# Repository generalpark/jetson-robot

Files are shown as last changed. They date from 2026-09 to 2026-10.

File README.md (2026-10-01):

# Jetson ROS2 Robot

사람이 말로 준 주행 명령을 **로봇 안의 언어모델**이 제어 명령으로 바꾸고, **ESP32가 모터를 돌리는** 로봇을
부품 선정부터 펌웨어 · 모델 학습 · 엣지 추론 최적화까지 직접 만든 기록입니다.
연산은 Jetson Orin Nano, 실시간 제어는 MCU로 나눴습니다.

> 🚧 2026-10-01 기준 — 제어부 · 모델 · 추론 최적화 완료, 문장 → ESP32 경로 연결 확인. 조립 · 실주행 전

---

## 한눈에

| 영역 | 결과 | 자세히 |
|---|---|---|
| **펌웨어** | BTS7960 단락 방지 순서 강제, 500ms 무명령 시 자동 정지, 20kHz PWM을 계측 장비 없이 검증 (최대 오차 **1.25%p**) | [firmware/](firmware/README.md) |
| **모델 학습** | 자연어 → ROS 2 Twist JSON. 값 정확도 few-shot **2.0% → LoRA 74.7%** (전체 파라미터의 1.75%만 학습) | [finetune/](finetune/README.md) |
| **안전** | "오늘 날씨 어때"에도 움직이던 문제. 거부 학습으로 주행 아닌 문장 60건 중 움직임 **57~100% → 0%**, 학습 어휘 정확도 100% 유지 | [finetune/](finetune/README.md#주행이-아닌-문장-거부-2026-10-01) |
| **재현성** | 한 번씩 학습해 본 "거부 학습 후 −3.4%p"를 시드 3회로 다시 재니 편차(같은 설정도 70~80%)였다. 확신도 되묻기는 부호 오류를 절반으로 줄이지만 모델이 확신을 갖고 틀려 기본값에선 뺐다 | [finetune/](finetune/README.md#시드-반복--한-번-학습한-비교는-믿을-수-없었다-2026-10-01) |
| **평가 설계** | 검증 손실 0.000027이지만 학습 어휘 **100%** vs 미학습 어휘 **49.3%**. 오답 38건 전부 미학습 어휘 | [finetune/](finetune/README.md) |
| **엣지 추론** | **4,115ms → 408ms (10.1배)**, 모델 942 → 374MB, 정확도 −0.7%p. 병목 4개를 측정으로 하나씩 제거 | [BENCHMARK](finetune/BENCHMARK.md) |
| **경로 통합** | 문장 → ESP32 수신까지 실측. 드문드문 오는 요청은 GPU 클럭이 안 올라 **810 → 420ms**(서버 동작 중에만 클럭 고정). 주행 시간이 ROS 기동 시간만큼 짧아지던 버그 수정. 상주 브릿지로 **2.5 → 0.6초**, 달리는 중 정지 0.17초 | [BENCHMARK](finetune/BENCHMARK.md#실제-주행-경로에서-2026-10-01) |
| **장애 진단** | 학습 중 무로그 재부팅. 전원 가설을 측정으로 기각하고, PyTorch 캐시 팽창(5.6GB)이 원인임을 찾아 해결 | [finetune/](finetune/README.md#학습-중-보드-리셋--원인은-메모리였다) |

---

## 전체 흐름

```
 "앞으로 천천히 3초 동안 가"
          │
          ▼   Jetson Orin Nano 8GB
 ┌───────────────────────────────┐
 │ Qwen2.5-0.5B + LoRA           │  → {"linear": 0.15, "angular": 0.0, "duration": 3.0}
 │ llama.cpp Q4_K_M (상주 서버)  │
 └───────────────────────────────┘
          │  ROS 2 /cmd_vel (geometry_msgs/Twist)
          ▼
   micro-ROS Agent ──USB 시리얼──▶ ESP32 ──PWM 20kHz──▶ BTS7960 ×2 ──▶ DC 모터 ×4
```

`firmware/nl2cmdvel.sh` 한 줄로 이 경로 전체가 실행됩니다. 모델과 ROS 노드가 모두 상주해,
문장 입력부터 ESP32가 첫 명령을 받기까지 **0.6초**(처음 연결했을 때 2.2~2.7초)입니다.
"멈춰" 같은 정지어는 모델을 거치지 않고 **0.17초** 만에 진행 중인 명령을 덮어씁니다.

---

## 시스템 구조

```
┌─────────────────────────┐        ┌──────────────────────┐
│  Jetson Orin Nano 8GB   │        │   ESP32 DevKitC      │
│                         │ USB    │                      │
│  · ROS2 Humble          │◄──────►│  · micro-ROS Client  │
│  · 명령 해석 (언어모델)   │ serial │  · PWM 모터 제어      │
│  · micro-ROS Agent      │115200  │  · 무명령 시 자동 정지 │
└─────────────────────────┘        └──────────────────────┘
         │                                    │
    카메라 / IMU                        모터 드라이버 ×2
                                              │
                                        DC 모터 ×4 (엔코더)
```

**왜 분리했는가** — 모터 PWM 제어와 엔코더 펄스 카운트는 수 μs 단위의 응답이 필요한데, 리눅스 유저스페이스는 이를 보장하지 못합니다. 실시간성이 필요한 루프는 MCU에 두고, Jetson은 인지·판단만 담당하도록 역할을 나눴습니다. 두 계층은 micro-ROS로 이어져 ROS2 토픽으로 통신합니다.

---

## 하드웨어 구성과 선정 근거

| 부품 | 선정 | 근거 |
|---|---|---|
| **연산** | Jetson Orin Nano 8GB | 온디바이스 추론을 위한 GPU 필요 |
| **MCU** | ESP32 DevKitC (WROOM-32D, CP2102) | micro-ROS 지원 확인. **WROOM-32U는 외부안테나형, ESP32-P4는 micro-ROS 미지원**이라 제외 |
| **모터** | JGA25-370 12V 170RPM, 엔코더 내장 ×4 | 홀 엔코더 11PPR × 감속비 35 = **바퀴 1회전당 385펄스**. 오도메트리 분해능 확보 |
| **드라이버** | BTS7960 (IBT-2) ×2 | 좌/우 각 2모터 병렬 구동 |
| **카메라** | IMX219 120° **22핀** | Orin Nano는 22핀 CSI. 15핀 모듈은 변환 케이블이 추가로 필요 |
| **IMU** | MPU6050 | 자세 추정 |

### 전원 설계

모터와 연산 장치의 전원을 **물리적으로 분리**했습니다.

- **모터계** — 12V 18650 3S2P (BMS 내장)
- **연산계** — USB-PD 파워뱅크 + PD 트리거 케이블

분리한 이유는 두 가지입니다. 첫째, 모터 기동 시 순간 전류가 크게 흘러 연산 장치의 전압이 흔들립니다. 둘째, **대부분의 파워뱅크는 2포트를 동시에 쓰면 출력이 5V로 강등**되는데, Jetson은 9~20V 입력을 요구하므로 한 배터리에서 둘 다 뽑으면 부팅 자체가 불안정해집니다.

---

## 셋업 과정에서 해결한 것

### Docker 데이터 경로를 NVMe로 이전
jetson-containers 이미지는 개당 10~15GB입니다. 64GB microSD로는 두 개도 못 올립니다.
NVMe SSD를 `/mnt/nvme`로 마운트하고 Docker `data-root`를 그쪽으로 옮겼습니다. `default-runtime`을 `nvidia`로 지정해 컨테이너에서 GPU를 바로 쓸 수 있게 했습니다.

### L4T 패키지 버전 고정
`apt upgrade`가 `nvidia-l4t-*` 패키지를 건드리면 CUDA 환경이 깨지고 부팅이 안 되는 사례가 보고돼 있습니다.
관련 패키지 55개를 `apt-mark hold`로 잠갔습니다. 일반 패키지 설치는 그대로 가능합니다.
같은 이유로 `torch.compile`에 필요한 Triton을 맞추려 PyTorch를 올리지 않고, C++ 런타임(llama.cpp)으로 우회했습니다.

### 학습 중 메모리 상한
Jetson에는 전용 VRAM이 없어 GPU가 시스템 RAM을 나눠 씁니다. PyTorch 캐싱 할당기를 그대로 두면
학습 중 5.6GB까지 불어나 OS가 멈췄습니다. 학습 스크립트는 기본으로 할당기에 상한(60%)을 겁니다.

### 전력 모드
`nvpmodel -m 2` (MAXN_SUPER)로 설정해 CPU 1.73GHz / GPU 1020MHz를 사용합니다.

### 시리얼 권한
ESP32(CP2102) 인식을 위해 `cp210x` 드라이버 로드를 확인하고, 사용자를 `dialout` 그룹에 추가해 `sudo` 없이 시리얼에 접근하도록 했습니다.

---

## 저장소 구조

```
firmware/    ESP32 펌웨어 — 시리얼 단독 테스트용(motor_ctrl), micro-ROS 노드(motor_uros),
             자연어 → /cmd_vel 스크립트(nl2cmdvel.sh)
finetune/    데이터 생성 · LoRA 학습 · 평가 · 추론 최적화 · 진단 스크립트, 측정 기록
scripts/     Jetson 쪽 USB 확인, micro-ROS Agent, 명령 해석 서버(llama-server), ROS 2 셸
```

## 스크립트

| 스크립트 | 용도 |
|---|---|
| `scripts/check_usb.sh` | ESP32(USB 시리얼) 인식 확인 — 장치 노드, `lsusb`, 커널 로그를 한 번에 |
| `scripts/uros_agent.sh` | micro-ROS Agent 실행 (컨테이너) |
| `scripts/llama_server.sh` | 명령 해석 모델(Q4_K_M) 상주. 떠 있는 동안만 GPU 최저 클럭 고정, 종료 시 원복 |
| `scripts/cmd_bridge.sh` | `/cmd_vel` 브릿지 상주. 명령을 로컬 TCP로 받아 10 Hz 발행, 새 명령이 진행 중 명령을 덮어씀 |
| `scripts/ros2sh.sh` | ROS2 셸 진입 — 토픽 확인용 |

### 통신 검증 순서

```bash
./scripts/check_usb.sh          # /dev/ttyUSB0 인식 확인
./scripts/uros_agent.sh         # 터미널 A — Agent 대기
./scripts/ros2sh.sh             # 터미널 B
  └─ ros2 topic list            # ESP32가 만든 토픽이 보이면 성공
```

> micro-ROS Agent 옵션은 `--dev`가 아니라 **`-D`** 입니다. 문서마다 다르게 적혀 있어 실행이 안 되는 원인이 됩니다.

> ESP32는 **부팅할 때 한 번만** Agent에 접속합니다. Agent를 먼저 띄운 뒤 ESP32의 EN(리셋) 버튼을 누르세요.

### 자연어 주행

```bash
./scripts/uros_agent.sh                           # 터미널 A — Agent (띄운 뒤 ESP32 리셋)
./scripts/llama_server.sh                         # 터미널 B — 명령 해석 서버
./scripts/cmd_bridge.sh                           # 터미널 C — /cmd_vel 브릿지
./firmware/nl2cmdvel.sh "앞으로 천천히 2초 동안 가"   # 터미널 D
./firmware/nl2cmdvel.sh "멈춰"                     # 달리는 중에도 바로 정지
```

---

## 환경

| | |
|---|---|
| L4T | R36.4.3 (JetPack 6.2) |
| 커널 | 5.15.148-tegra |
| CUDA | 12.6 |
| PyTorch | 2.4.0 (NVIDIA Jetson 빌드, 컨테이너) |
| llama.cpp | CUDA 빌드, `sm_87` |
| ROS2 | Humble |
| micro-ROS Agent | `microros/micro-ros-agent:humble` |
| ROS2 이미지 | `dustynv/ros:humble-ros-base-l4t-r36.3.0` |

---

## 진행 상황

- [x] Jetson 개발 환경 구축 (JetPack 6.2, NVMe 이전, 패키지 고정)
- [x] micro-ROS Agent 컨테이너 구동, 시리얼 드라이버·권한 설정
- [x] 하드웨어 사양 선정
- [x] ESP32 펌웨어 — PWM 모터 제어, 드라이버 단락 방지, 통신 단절 시 정지, PWM 자가검증
- [x] micro-ROS `/cmd_vel` 구독 · 차동 구동 변환
- [x] 자연어 → 제어 명령 모델 학습 · 평가 (LoRA), 데이터 양 스윕
- [x] 엣지 추론 최적화 (llama.cpp Q4, 10.1배)
- [x] 학습 중 보드 리셋 원인 규명 · 해결 (메모리)
- [ ] 구동부 조립 · 실주행 (부품 입고 완료)
- [ ] 엔코더 인터럽트 카운트 → 오도메트리 발행
- [x] llama.cpp 추론을 `/cmd_vel` 경로에 연결, 문장 → ESP32 수신 실측
- [x] 주행이 아닌 문장 거부 학습 (배포 모델 교체), 정지어는 규칙으로 먼저 처리
- [x] 상주 `/cmd_vel` 브릿지 — 문장 → ESP32 0.6초, 달리는 중 정지
- [ ] 카메라 · IMU 연동
- [ ] SLAM / 경로계획

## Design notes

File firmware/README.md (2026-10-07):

# ESP32 주행 제어 펌웨어

로봇의 구동부를 맡는 마이크로컨트롤러 쪽 코드다. 두 가지 형태로 만들었다.

| 디렉토리 | 입력 | 용도 |
|---|---|---|
| `motor_ctrl` | USB 시리얼 명령 | 단독 테스트, PWM 자가검증 |
| `motor_uros` | ROS 2 `/cmd_vel` | 실제 주행. micro-ROS 노드로 동작 |

PWM 핀 배치·설정과 안전장치는 둘이 같다. `motor_uros`만 드라이버 EN을 GPIO로 제어한다(아래 "배선").

## 드라이버를 지키는 부분

BTS7960은 정·역을 `RPWM` / `LPWM` 두 핀으로 나눠 받는다. 한쪽에 듀티를 주는 동안
반대쪽은 반드시 0이어야 한다. 둘 다 0이 아니면 하이사이드와 로우사이드가 동시에
열려 드라이버가 단락된다.

```cpp
if (speed >= 0) { ledcWrite(ch_rev, 0); ledcWrite(ch_fwd, speed); }
else            { ledcWrite(ch_fwd, 0); ledcWrite(ch_rev, -speed); }
```

한쪽을 먼저 0으로 내린 뒤 반대쪽을 올린다. 순서가 바뀌면 전환하는 순간 양쪽이
짧게 같이 살아난다.

PWM은 20kHz로 둔다. 가청대역 위라 모터에서 나는 고주파 소음이 줄어든다.

## 배선 (실물로 확인, 2026-10-03)

| ESP32 | L 드라이버 | R 드라이버 |
|---|---|---|
| RPWM | 25 | 32 |
| LPWM | 26 | 33 |
| R_EN | 27 | 16 |
| L_EN | 18 | 17 |
| VCC (로직) | 3V3 | **23 (GPIO HIGH)** |
| GND | GND | GND |

- **EN은 펌웨어가 켠다.** 가진 점퍼선이 암-암뿐이라 3V3 한 핀을 VCC·R_EN·L_EN 여섯 곳으로
  나눌 수 없었다. EN을 GPIO에 하나씩 물리고 micro-ROS 연결이 끝난 뒤에 HIGH로 올린다.
  부팅 중이나 상위와 연결되기 전에는 드라이버가 꺼져 있다
- R 드라이버 로직 전원은 GPIO23으로 준다. 로직부(74HC244 + BTS7960 입력)는 수 mA 이하라
  GPIO로 충분하다. 브레드보드가 생기면 3V3로 옮길 것
- R_IS / L_IS는 쓰지 않는다
- HW-039 헤더 옆 표는 핀 위치 그대로다. 위 줄 LPWM · L_EN · L_IS · GND, 아래 줄 RPWM · R_EN · R_IS · VCC,
  VCC/GND가 표 쪽 끝이다
- **출력 단자는 앞면(칩 쪽)에서 콘덴서 반대편부터 M− · M+ · B+ · B−**다. 뒷면 인쇄(B− · B+ · M+ · M−)와
  좌우가 뒤집혀 보인다. 모터를 B+/B−에 물리면 명령과 무관하게 배터리 전압으로 돈다(실제로 겪음)
- 모터 6핀(JGA25-370 엔코더): 빨강 M1 · 흰색 M2가 모터 전원, 검정 GND · 노랑 A · 초록 B · 파랑 VCC가 엔코더
- 섀시에 달면 좌우 모터가 거울상이라, 배선을 같게(빨강 → M+) 하면 오른쪽이 거꾸로 돈다.
  선을 바꾸지 않고 펌웨어 `INVERT_R`로 뒤집는다. 좌우 바퀴 중심 간격 `WHEEL_BASE`는 박스 섀시 실측 0.24 m
- 4륜 스키드 조향이라 제자리 회전에서 바퀴가 미끄러진다. 90도 명령에 45도만 돌아(3회 같음)
  `TURN_EFF` 0.56으로 유효 간격을 늘렸고, 보정 후 90도 남짓. `MAX_SPEED`는 직진 실측(90%)으로 0.50.
  **둘 다 박스 섀시·실내 바닥 기준이라 섀시나 바닥이 바뀌면 다시 잰다**

## 명령이 끊기면 멈춘다

```cpp
if (!stopped && millis() - last_cmd_ms > CMD_TIMEOUT_MS) driveStop();
```

500ms 동안 명령이 없으면 스스로 정지한다. 상위 제어기가 죽거나 USB가 빠졌을 때
**마지막 속도로 계속 달리는 것이 가장 위험하다**고 봤다. 멈춰 있는 로봇은 늦어질 뿐이지만
제어를 잃은 채 움직이는 로봇은 사고가 된다.

## PWM이 실제로 나가는지 확인한 방법

보드에 사용자 LED가 없고 오실로스코프도 로직 애널라이저도 없었다.
그래서 **출력 핀을 입력 핀에 점퍼선으로 연결해, 보드가 자기 출력을 자기가 읽게** 했다.

```
GPIO25 (PWM 출력) ──점퍼선── GPIO34 (입력 전용)
```

PWM 한 주기(20kHz = 50µs)보다 훨씬 긴 시간 동안 20,000번 읽어 HIGH 비율을 센다.
샘플링이 PWM과 동기화돼 있지 않으므로, 표본이 충분하면 그 비율이 듀티에 수렴한다.

| duty | 측정 | 기대 | 오차 |
|---:|---:|---:|---:|
| 0 | 0.0000 | 0.0000 | 0 |
| 32 | 0.1308 | 0.1255 | +0.53%p |
| 64 | 0.2603 | 0.2510 | +0.93%p |
| 96 | 0.3875 | 0.3765 | +1.10%p |
| 128 | 0.5138 | 0.5020 | +1.19%p |
| 160 | 0.6399 | 0.6275 | +1.25%p |
| 192 | 0.7574 | 0.7529 | +0.44%p |
| 224 | 0.8780 | 0.8784 | −0.04%p |
| 255 | 1.0000 | 1.0000 | 0 |

9개 지점 모두 선형이고 최대 오차는 1.25%p다.

오차가 양끝에서 0이고 중간에서 커지는 것은 측정 방식 때문이다. duty 0과 255는
전환 자체가 없어 오차가 생길 수 없고, 중간 구간은 상승·하강 에지에서 읽힐 확률이
있어 HIGH 쪽으로 미세하게 치우친다. 출력의 오차가 아니라 샘플링의 한계다.

실행: 시리얼로 `V` 를 보내면 위 표를 출력한다.

## ROS 2 연동

`motor_uros` 는 `/cmd_vel`(`geometry_msgs/Twist`)을 구독해 차동 구동으로 바꾼다.

```
v_left  = v - w * L / 2
v_right = v + w * L / 2
```

`MAX_SPEED`는 JGA25-370(12V, 170RPM)과 65mm 바퀴 기준 이론값 0.578 m/s에서
0.55로 잡았다. 무부하 회전수라 실제로는 더 낮다. **조립 후 실측해서 고칠 값이다.**

Jetson에서 micro-ROS Agent를 띄우면 보드가 ROS 2 노드로 참여한다.

```bash
~/robot/uros_agent.sh /dev/ttyUSB0
ros2 topic pub -r 10 /cmd_vel geometry_msgs/msg/Twist '{linear: {x: 0.3}}'
```

## 빌드 메모

- micro-ROS 빌드는 **Windows에서 동작하지 않는다.** 빌드 스크립트가 POSIX 셸을
  전제로 해서 `. install/setup.sh` 에서 멈춘다. Jetson(Linux)에서 빌드했다
- PlatformIO를 venv에 설치하면 `~/.platformio/penv` 가 없어 micro-ROS 의존성
  빌드가 실패한다. 해당 경로로 심볼릭 링크를 걸어 해결했다
- 이 보드는 DTR/RTS 자동 리셋이 동작하지 않는다. 업로드할 때 **BOOT를 누른 채로**
  둬야 다운로드 모드로 들어간다. 단, 2026-10-01 Jetson에서 `pio run -t upload`(esptool
  `default_reset`)는 BOOT 없이 들어갔다. 안 되면 BOOT를 누른다
- 시리얼 포트를 그냥 열면 DTR/RTS가 올라가면서 보드가 리셋되거나 부트 모드가 바뀐다.
  둘 다 내린 상태로 연 뒤 RTS를 한 번만 토글해 의도적으로 리셋한다
- micro-ROS Agent가 포트를 잡고 있으면 업로드가 실패한다. 먼저 컨테이너를 내린다

## 파일

| 파일 | 내용 |
|---|---|
| `motor_ctrl/src/main.cpp` | 시리얼 제어 + PWM 자가검증 |
| `motor_uros/src/main.cpp` | micro-ROS 노드, `/cmd_vel` 구독 |
| `test_motor.py` | 드라이버·모터 없이 로직 검증 (6개 항목) |
| `demo_led.py` | 듀티 변화 시연 |
| `test_uros.sh` | ROS 2 토픽 연동 확인 |
| `nl2cmdvel.sh` | 자연어 → 파인튜닝 모델(llama-server) → `/cmd_vel` |
| `cmd_vel_bridge.py` | 상주 `/cmd_vel` 브릿지. 로컬 TCP로 명령을 받아 10 Hz 발행, 새 명령이 덮어씀 |
| `pub_cmd_vel.py` | `/cmd_vel`을 정확히 duration초 발행 후 정지 명령 (ESP32 연결 뒤부터 계측) |

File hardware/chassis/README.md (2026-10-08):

# 아크릴 2층 섀시

박스 섀시로 배치·치수를 확인한 뒤(2026-10-07~08) 그대로 옮긴 레이저 재단 도면이다.

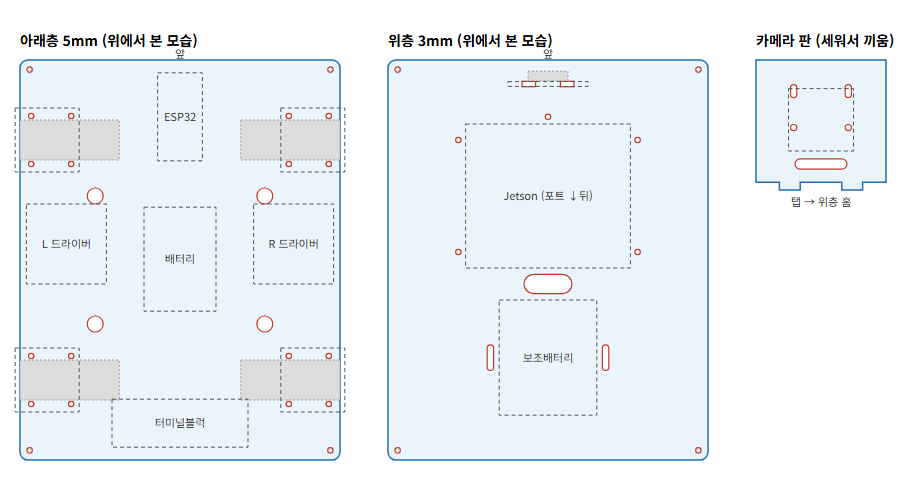
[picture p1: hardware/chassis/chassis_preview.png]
미리보기


- `chassis.dxf` — 재단용(R12, 단위 mm). 왼쪽부터 아래층 5T 200×250, 위층 3T 200×250, 카메라 판 3T 50×50
- `make_chassis.py` — 위 두 파일을 만드는 스크립트. 치수는 맨 위 상수에 모여 있다

| 항목 | 값 | 근거 |
|---|---|---|
| 바퀴 축선 | 앞에서 50 / 200mm | 박스 섀시 배치 |
| 브래킷 구멍 | 판 가장자리에서 7 · 32mm, 축선 ±15mm, M3 | 브래킷 실측 (바닥판 40×40, 구멍 30×25) |
| 브래킷 장착 | 바닥판은 판 위, 모터는 판 아래 | 바닥판-모터 틈 20mm에 5T 판이 들어감 |
| 층 사이 | 약 60mm | 아래층 최고 높이 40mm(배터리·드라이버·터미널블럭) + 배선 여유 |
| Jetson | 틀 103×90mm, 찍찍이 + 멈춤 기둥 5개 | 개발자 키트에 나사 구멍이 없음(플라스틱 틀) |
| 카메라 | 판을 세워 홈에 끼움, 위 구멍은 세로 긴 구멍 | 구멍 간격 실측 14mm가 RPi v2 표준(12.5)과 달라 오차 흡수 |

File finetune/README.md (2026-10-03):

# 자연어 주행 명령 → 제어 명령 변환 (LoRA 파인튜닝)

Jetson Orin Nano 8GB에서 소형 언어모델을 파인튜닝해, 사람이 말하듯 준 주행 명령을
로봇이 그대로 받아쓸 수 있는 제어 명령(JSON)으로 바꾼다.

```
"5초 동안 앞으로 천천히 가면서 왼쪽으로 틀어"
   ↓
{"linear": 0.15, "angular": 0.24, "duration": 5.0}
```

출력 형식은 ROS2 `geometry_msgs/Twist`의 선속도·각속도를 그대로 따른다.

## 왜 파인튜닝까지 했나

먼저 학습 없이 프롬프트만으로 되는지 확인했다. 같은 시스템 프롬프트를 쓰고,
예시를 주지 않은 경우와 3개 준 경우를 각각 측정했다.

예시를 주자 **형식은 완전히 교정됐지만(스키마 62.7% → 100%) 값 정확도는 거의 그대로였다**
(완전일치 1.3% → 2.0%). 형식은 프롬프트로 잡히지만, "천천히"가 0.15 m/s라는
도메인 고유의 대응은 프롬프트로 전달되지 않는다고 보고 학습으로 넘어갔다.

## 결과

| | JSON 파싱 | 스키마 일치 | 방향(부호) | 값 완전일치 |
|---|---:|---:|---:|---:|
| 형식 지시만 (zero-shot) | 100.0% | 62.7% | 14.0% | 1.3% |
| 예시 3개 (few-shot) | 100.0% | 100.0% | 42.0% | 2.0% |
| **LoRA 학습 후** | **100.0%** | **100.0%** | **86.0%** | **74.7%** |

측정은 테스트 150건, 그리디 디코딩 기준이다.

## 검증 손실이 말해주지 않은 것

학습이 끝났을 때 검증 손실은 0.000027이었다. 숫자만 보면 다 맞히는 모델이다.
그런데 같은 모델의 테스트 완전일치는 74.7%였다.

검증셋이 학습과 같은 어휘로 만들어졌기 때문이다. 테스트셋을 **학습에 나온 표현 75건**과
**학습에 없던 표현 75건**으로 절반씩 나눠 다시 재보니 차이가 분명했다.

| LoRA | 방향(부호) | 값 완전일치 |
|---|---:|---:|
| 학습에 나온 표현 (75건) | 100.0% | **100.0%** |
| 학습에 없던 표현 (75건) | 72.0% | **49.3%** |

**틀린 38건은 전부 학습에 없던 표현이었다.** 학습 어휘 안에서는 한 건도 틀리지 않았다.

### 어떻게 틀렸나

| 입력 | 정답 | 생성 | 무슨 일이 났나 |
|---|---|---|---|
| 앞으로 **살살** 가면서 좌측으로 틀어 | linear 0.15 | 0.3 | 모르는 속도어 → 기본값으로 대체 |
| **뒤쪽으로** 가 | linear −0.3 | angular −0.72 | 모르는 방향어 → 다른 항목으로 흘림 |
| 오른쪽으로 **전속력으로** 돌아 | angular −1.2 | −0.72 | 모르는 강도어 → 중간값 |

로봇에서는 두 번째가 가장 위험하다. 후진 명령이 회전 명령이 되면 값이 조금
어긋나는 것과는 다른 종류의 사고가 된다. 속도를 덜 내는 것은 느려질 뿐이지만,
명령의 종류가 바뀌면 의도하지 않은 방향으로 움직인다.

### 대조군을 다시 만든 이유

처음 만든 테스트셋은 150건 중 146건에 새 어휘가 섞여 있었다. 문장이 방향·속도·
어미 등 여러 자리를 쓰다 보니, 한 자리만 새 어휘여도 전체가 "새 표현"으로 분류됐다.
대조군이 4건뿐이어서 비교가 성립하지 않았고, 두 그룹을 75건씩 맞춰 다시 생성했다.

## 지표를 이렇게 나눈 이유

한 개의 정확도만 보면 무엇이 고쳐졌는지 알 수 없다. 실패가 어느 단계에서
나는지 구분하려고 네 단계로 나눴다.

| 지표 | 보는 것 |
|---|---|
| JSON 파싱 | 출력이 JSON이기는 한가 |
| 스키마 일치 | 필요한 키 3개가 모두 있고 숫자인가 |
| 방향(부호) | 앞뒤·좌우를 반대로 보내지 않는가 |
| 값 완전일치 | 속도·시간까지 맞는가 (허용 오차 0.02) |

로봇에서는 **부호가 틀리는 것이 값이 조금 틀리는 것보다 위험하다.**
속도가 0.3이어야 하는데 0.25인 것은 느리게 갈 뿐이지만, 부호가 뒤집히면
반대로 간다. 그래서 부호를 따로 뒀다.

## 어휘를 넓히면 나아지는가 (실험)

일반화가 안 되는 원인이 학습 어휘가 좁아서인지 확인했다.
**데이터 양은 800건으로 고정하고 어휘만 넓혔다**(고유 토큰 33 → 47).
양을 함께 늘리면 무엇이 효과를 냈는지 분리할 수 없다. 테스트셋도 그대로 뒀다.

| 학습에 없던 표현 75건 | 방향(부호) | 값 완전일치 |
|---|---:|---:|
| 기본 어휘 | 72.0% | 49.3% |
| 어휘 확장 | **78.7%** | **49.3%** |

방향은 6.7%p 올랐고 값 정확도는 변하지 않았다. 고쳐진 7건은 전부 방향 오류였고,
그 중 다수는 방향만 바로잡힌 채 값은 여전히 틀렸다.

| 입력 | 기본 | 확장 | 정답 |
|---|---|---|---|
| 우측으로 천천히 돌아 | angular +0.36 | **−0.36** | −0.36 |
| 앞쪽으로 살살 가봐 | angular 0.36 | linear **0.3** | linear 0.15 |

값이 틀린 38건에 들어 있던 새 단어는 `살살`(15), `뒤쪽으로`(14), `전속력으로`(11) 순이었다.
속도어가 남았다.

| 종류 | 어휘 확장 효과 | 이유 |
|---|---|---|
| 방향 (우측으로, 꺾어) | 개선 | `우`·`왼` 등 형태 단서가 있고 문장 내 위치로 유추된다 |
| 속도 등급 (살살, 전속력으로) | 없음 | 형태로 유추할 수 없고 단어의 뜻을 알아야 값이 정해진다 |

**여러 개 중 하나를 고르는 문제는 데이터 다양성으로 개선되지만, 단어를 수치로
옮기는 문제는 개선되지 않았다.** 후자는 데이터를 더 모으는 대신 사전 정규화나,
모르는 단어를 만났을 때 지어내지 않고 되묻는 장치가 맞다고 본다. 로봇에서는
틀린 값으로 움직이는 것보다 멈추고 확인하는 편이 낫다.

재현:

```bash
./run_rich.sh
```

## 데이터

합성 데이터 1,050건(학습 800 / 검증 100 / 테스트 150)을 규칙으로 생성했다.

테스트셋에는 **학습에 한 번도 나오지 않은 표현**을 섞었다(`살살`, `전속력으로`,
`좌측으로`, `앞쪽으로` 등). 학습 어휘로만 평가하면 외운 것인지 규칙을 익힌 것인지
구분할 수 없기 때문이다.

## 8GB에서 돌리기

전체 파라미터 학습은 메모리에 들어가지 않아 LoRA로 어댑터만 학습했다.

- 학습 대상 **8,798,208 / 502,830,976 = 1.75%**
- fp16, gradient checkpointing, batch 4 × 누적 4
- 손실은 정답 JSON 구간에만 건다. 프롬프트까지 학습하면 모델이 질문을 따라 쓴다

## 실행

```bash
python3 gen_data.py --out .          # 데이터 생성
./run_eval.sh zeroshot fewshot       # 학습 전 기준선
./run_train.sh                       # LoRA 학습
./run_eval.sh lora                   # 학습 후 측정
```

## 구성

| 파일 | 내용 |
|---|---|
| `gen_data.py` | 데이터 생성. 학습/테스트 어휘 분리 |
| `train_lora.py` | LoRA 학습. 프롬프트 구간 손실 제외 |
| `evaluate.py` | 4단계 지표 측정. zero-shot/few-shot/LoRA 공통 |
| `analyze.py` | 아는 표현 / 모르는 표현을 나눠 비교 |
| `run_eval.sh`, `run_train.sh` | 컨테이너 실행 |
| `run_rich.sh` | 어휘 확장 실험 (생성 → 학습 → 평가) |
| `offtopic.py` | 주행이 아닌 문장 목록 (학습용 191 / 평가용 60, 문장 단위로 분리) |
| `run_reject.sh`, `report_reject.py` | 거부 학습 실험과 전후 비교표 |
| `run_seeds.sh`, `report_seeds.py` | 시드 반복 학습·평가와 평균 ± 표준편차 |
| `run_logprobs.sh`, `analyze_confidence.py` | 토큰 확률 수집과 확신도 기반 되묻기 분석 |
| `run_1p5b.sh` | 1.5B 비교 실험 (8GB에서는 메모리 부족으로 중단, 큰 GPU용) |

## 데이터 양 스윕 (2026-09-30)

같은 설정에서 학습 데이터 양만 바꾸고 같은 테스트셋 150건으로 쟀다.

| 학습 데이터 | 값 완전일치 | 방향(부호) | 두 배로 늘릴 때 |
|---|---|---|---|
| 100개 | 41.3% | 71.3% | — |
| 200개 | 65.3% | 79.3% | +24.0%p |
| 400개 | 71.3% | 86.7% | +6.0%p |
| 800개 | 74.7% | 86.0% | +3.4%p |

두 배로 늘릴 때마다 얻는 폭이 줄고, 방향 정확도는 400개에서 포화한다. 틀린 답이 전부 학습에 없던
어휘에서 나왔던 것과 같은 결론이다. 같은 어휘로 양을 늘리는 것보다 **어휘 다양성**이 다음 개선 수단이다.

## 주행이 아닌 문장 거부 (2026-10-01)

실제 주행 경로에 붙여 보니 "오늘 날씨 어때"에도 좌회전 명령이 나왔다. 학습 데이터가 전부
주행 명령이라 모델이 모든 입력을 주행으로 읽는다. 주행이 아닌 문장 60개로 재보니 이랬다.

| 기존 모델 | 건수 | 움직이는 명령을 낸 비율 |
|---|---:|---:|
| 잡담 · 질문 · 다른 기기 명령 ("세탁기 돌려줘") | 35 | 57.1% |
| 주행 어휘가 든 비주행 문장 ("뒤로 가기 버튼 눌러줘", "10초 동안 숨 참아봐") | 25 | **100%** |

**방법** — 주행 데이터 800건과 테스트셋 150건은 한 글자도 바꾸지 않고, 정답이 `{"reject": true}`인
문장 191개만 더해 다시 학습했다(`offtopic.py`). 거부 효과만 따로 재기 위해서다.

- 평가용 60개는 학습 문장과 겹치지 않는다. 화면 버튼, 방향이 붙은 기기 명령("오른쪽 스피커만 켜줘")처럼
  **학습에 없는 유형**도 넣었다
- 정지 단어("멈춰", "그만" 등)가 든 문장은 거부 데이터에 넣지 않았다. 헷갈리는 문장이면 거부보다
  멈추는 편이 안전하므로, 정지 단어와 거부가 함께 학습되지 않게 했다

**결과**

| | 주행 완전일치 | 부호 | 잘못 거부 | 잡담 거부 | 잡담인데 움직임 | 헷갈림 거부 | 헷갈림인데 움직임 |
|---|---:|---:|---:|---:|---:|---:|---:|
| 기존 모델 | 74.7% | 86.0% | 0% | 0% | 57.1% | 0% | 100% |
| 거부 학습 | 71.3% | 86.7% | 0.7% | **100%** | **0%** | **100%** | **0%** |
| 거부 학습 Q4_K_M | 71.3% | 84.0% | 1.3% | 100% | 0% | 100% | 0% |
| **+ 정지어 규칙 (배포)** | 72.0% | 84.7% | 0.7% | 100% | 0% | 100% | 0% |

- **주행이 아닌 문장 60건을 전부 거부했다.** 학습에 없던 유형도 포함이다. 다만 60건은 작은 표본이다
- **학습 어휘 75건은 전후 모두 100%다.** 완전일치가 3.4%p 준 것은 전부 학습에 없던 어휘 구간에서
  나왔다(9건이 바뀌어 7건 잃고 2건 얻음). → **시드 반복으로 다시 재 보니 편차였다.** 아래 "시드 반복" 참고
- 잘못 거부한 것: `세워`(학습에 없던 정지어), Q4에서 `앞쪽으로 살살 가봐`(세 단어 모두 처음 보는 어휘).
  후자는 앞에서 말한 "모르는 말이면 지어내지 말고 멈춘다"에 가까운 동작이다. **전자는 정지 명령을
  거부한 것이라 위험하다.** 그래서 정지는 모델에 맡기지 않는다. `infer.py`가 정지어(`멈춰`, `세워`, `중지` 등)를
  보면 모델을 부르지 않고 바로 정지 명령을 낸다. 테스트 150건에서 정지가 아닌 명령에 걸린 것은 0건이었고,
  "계획을 세워"처럼 엉뚱하게 걸려도 결과는 정지라 안전하다. 틀린 정지는 불편하고, 틀린 주행은 위험하다
- 거부는 응답도 빠르다. 짧은 JSON이라 요청당 약 170ms(주행 명령은 약 400ms)

재현:

```bash
./run_reject.sh     # 데이터 → 기준선 → 학습 → 평가 → GGUF 변환 → GGUF 평가 → 비교표
```

## 시드 반복 — 한 번 학습한 비교는 믿을 수 없었다 (2026-10-01)

위의 "완전일치 −3.4%p"는 각각 한 번씩 학습한 결과를 비교한 것이다. 같은 설정을 시드만 바꿔
3번씩 다시 학습했다(`run_seeds.sh`, `train_lora.py --seed`). 테스트셋은 그대로다.

| 시드 3회 평균 ± 표준편차 | 완전일치 | 학습 어휘 | 처음 보는 어휘 | 부호 | 비주행 거부 | 비주행인데 움직임 |
|---|---:|---:|---:|---:|---:|---:|
| 기존 | 72.0 ± 2.9 | 100 | 44.0 ± 5.8 | 84.4 ± 4.7 | 0 | 65.6 ± 17.3 |
| 거부 학습 | **77.8 ± 2.3** | 100 | **55.6 ± 4.7** | **91.8 ± 1.9** | 100 | **0** |

시드별 완전일치: 기존 70.0 / 70.7 / 75.3, 거부 학습 78.0 / 80.0 / 75.3. 처음 학습한 것은 기존 74.7, 거부 학습 71.3이었다.

- **−3.4%p는 거부 학습 탓이 아니었다.** 같은 설정이어도 학습마다 70~80% 사이에서 흔들리고, 처음 비교는
  운 좋은 기존 모델(74.7)과 운 나쁜 거부 모델(71.3)을 맞붙인 셈이었다
- 시드 3회 평균은 거부 학습 쪽이 높다. 다만 처음 실행까지 4개씩 넣으면 차이(약 3.5%p)가 편차 안이라,
  말할 수 있는 것은 **"거부 학습은 주행 정확도를 잃지 않는다"**까지다. 부호는 4개씩 넣어도 거부 학습 쪽이
  약 6%p 높다(84.8 vs 90.5)
- 학습 어휘는 모든 시드에서 100%다. 흔들리는 것은 처음 보는 어휘 구간뿐이다
- 배포 중인 거부 모델은 4개 중 점수가 가장 낮은 것이다. 그래도 바꾸지 않았다. 테스트 점수로 시드를 고르면
  테스트셋에 맞춰 고른 것이 되고, 그 점수는 더 이상 처음 보는 데이터의 성능이 아니다
- 교훈: 차이가 편차보다 작으면 한 번의 비교로 결론 내지 않는다. 이 프로젝트에서 앞서 낸 단일 비교들
  (어휘 확장, 데이터 양 스윕)도 같은 한계를 가진다

## 확신도로 되묻기 (2026-10-01)

틀린 답이 전부 처음 보는 어휘에서 나왔으니, 모델이 그 값을 고를 때 확률이 낮았다면 기준 아래에서는
움직이지 않고 되물으면 된다. **재학습 없이** 되는지 봤다(`run_logprobs.sh`, `analyze_confidence.py`).

- 확신도 = 출력한 숫자 토큰 확률의 최솟값. 결과를 보기 전에 이것을 주 지표로 정했다
- 기준은 테스트가 아니라 검증셋에서 정했다: "검증셋 정답의 99%(또는 95%)는 통과시키는 값"

배포 모델(거부 학습 Q4_K_M), 주행 테스트 150건:

| 되묻는 기준 | 되물음 (학습 어휘) | 잘못 움직임 | 부호 틀린 움직임 | 되물은 오답 | 되물은 정답 |
|---|---:|---:|---:|---:|---:|
| 없음 | 0 | 41 | 22 | — | — |
| 검증 정답 99% 통과 (τ=0.861) | 15 (2) | 34 | 18 | 7 | 8 |
| 검증 정답 95% 통과 (τ=0.991) | 28 (4) | 23 | **11** | 18 | 10 |

- 엄격한 기준이면 **부호가 틀린 움직임이 절반**이 되지만, 명령 5개 중 1개를 되묻는다
- **모델은 확신을 갖고 틀린다.** 오답의 확신도 중앙값이 0.995다. 처음 보는 속도어를 기본값으로 바꿀 때
  망설이지 않는다. 처음 보는 어휘 구간에서 정답·오답을 가르는 힘(AUROC)은 0.68에 그쳤다.
  모르는 것을 모른다는 신호가 약하다
- 거부 학습 전 모델은 AUROC 0.89로 더 잘 갈랐다. 다만 모델 한 쌍의 비교라 위의 교훈대로 판단을 보류한다
- 확률을 같이 받으면 요청당 0.1~0.2초가 더 든다
- 결론: 보조 수단으로는 쓸 만하지만 되묻는 비용이 커서 배포 기본값에는 넣지 않았다

### 디코딩 설정이 숨어 있었다

llama-server가 확률 0.63인 토큰 대신 0.37인 토큰을 고른 것을 보고 찾았다. Qwen2.5의 `generation_config.json`에
`repetition_penalty: 1.1`이 들어 있고, **transformers는 `do_sample=False`여도 이것을 적용하고, llama-server는
GGUF 메타데이터에서 같은 값을 기본값으로 가져온다.** 앞의 모든 수치는 이 조건에서 나왔다(양쪽이 같아 비교는 유효).
숫자 JSON에서는 앞에 나온 "0"을 깎아 값이 바뀔 수 있다. 끄고(1.0) 시드 3회로 재니 기존 70.7 ± 2.7,
거부 학습 77.6 ± 3.1로 **켠 경우와 편차 안**이었다. 그대로 둔다. `evaluate.py --repetition-penalty`,
`eval_gguf.py --repeat-penalty`로 바꿔 잴 수 있다.

## 모델 크기 1.5B — 이 보드에서는 학습하지 못했다 (2026-10-01)

처음 보는 속도어는 데이터 다양화로도, 확신도로도 안 잡혔다. 남은 가설은 "0.5B가 단어 뜻을 모른다"였고,
Qwen2.5-1.5B로 같은 실험을 하려 했다(`run_1p5b.sh`). **8GB 보드에서는 안전하게 학습할 수 없어 중단했다.**

```
1.5B LoRA, fp16      가중치 3.17 GB, 할당기 3.9 GB   →  시스템 가용 메모리 196 ~ 297 MB
배치 2 → 배치 1         위와 동일 (배치가 아니라 가중치 자체가 문제)
```

- 9/23 보드 리셋 때 가용 메모리가 170MB였다. 같은 구역이라 300MB 아래로 내려가면 컨테이너를 멈추는
  감시를 붙였고, 학습 첫 스텝부터 걸렸다
- 4비트로 올려 학습하는 QLoRA를 시도했다. PyPI의 bitsandbytes(0.50.2)는 설치는 되지만 Orin(sm_87)에서
  커널이 돌지 않았다(`named symbol not found`). Jetson용 빌드는 받을 수 있는 곳이 없었다
- 남은 방법은 더 큰 GPU에서 학습하고 어댑터만 가져와 Jetson에서 평가·지연을 재는 것이다.
  `run_1p5b.sh`는 그대로 쓸 수 있다

## 학습 중 보드 리셋 — 원인은 메모리였다

200개 학습이 매번 9스텝 근처에서 강제 종료되거나 보드가 로그 없이 재부팅됐다.

- 처음엔 전원 부족으로 판단했으나 틀렸다. 전류 센서(ina3221 ch1 `VDD_IN`)는 19V가 아니라 **모듈 5V 쪽**이라
  크래시 직전 2616mA는 약 13W다. 번들 어댑터(19V 2.37A, 45W)로 충분하다
- `--memlog`로 스텝별 메모리를 찍자 원인이 보였다. PyTorch 실사용(allocated)은 1.06GB로 일정한데
  **캐싱 할당기가 잡아둔 양(reserved)이 3.5→4.6→5.6GB로 불어났다.** Jetson에는 전용 VRAM이 없어
  reserved가 곧 시스템 RAM이고, 가용 메모리가 170MB까지 떨어지면서 OOM kill 또는 시스템 멈춤(→ 워치독 재부팅)이 났다
- 해결: `--mem-fraction 0.6`(기본값, `torch.cuda.set_per_process_memory_fraction`) +
  `PYTORCH_CUDA_ALLOC_CONF=garbage_collection_threshold:0.6`. reserved가 2.8GB에서 멈추고 39/39 완주.
  실제 필요 메모리(peak 2.16GB)는 그대로다
- 진단 도구: `diag_monitor.sh`(0.2초 간격 온도·전압·전류·GPU 클럭·가용 메모리, append+sync)

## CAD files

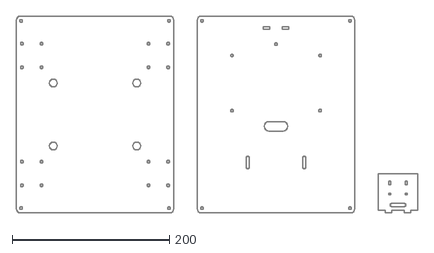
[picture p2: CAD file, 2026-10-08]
hardware/chassis/chassis.dxf
510.0 x 250.0

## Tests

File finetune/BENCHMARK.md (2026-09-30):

# 추론 최적화 측정 (Jetson Orin Nano 8GB)

대상: 자연어 주행명령 → ROS 2 Twist JSON 변환 모델 (Qwen2.5-0.5B + LoRA)
측정일: 2026-09-25 / CUDA 12.6.68, JetPack 6.2, MAXN_SUPER
조건: 배치 1 (실시간 제어 시나리오라 배칭 불가), 30샘플, 워밍업 후 측정

## 배경 — 왜 배치 1인가

주행 명령은 한 번에 하나씩 들어온다. 처리량보다 **요청당 지연**이 중요하고
배칭으로 숨길 수 없다. 그래서 throughput 벤치마크가 아니라 latency를 잰다.

## 결과

| 구성 | TTFT | E2E | tok/s | VRAM | 최대전류 |
|---|---|---|---|---|---|
| FP16 (LoRA 분리) | 165.8 ms | 4114.6 ms | 6.3 | 994 MB | 1688 mA |
| **+ LoRA 병합** | **87.0 ms** | **2094.1 ms** | **12.3** | 957 MB | 1768 mA |
| + GPU 클럭 고정 | 79.2 ms | 1918.4 ms | 13.4 | 957 MB | 2192 mA |

참고: 전류는 모듈 5V 쪽(`VDD_IN`, 약 4.95V)을 잰 값이다. 1688 mA ≈ 8.4 W.

## 관찰 1 — LoRA 병합은 사실상 공짜로 2배

```
속도 +96%   전력 +80 mA(+5%)   VRAM -37 MB
```

PEFT 어댑터는 매 forward마다 별도 matmul을 추가한다. 0.5B처럼 작은 모델에서는
base 연산 대비 이 오버헤드 비중이 커서, 가중치에 병합하는 것만으로 2배가 나왔다.

## 관찰 2 — 클럭 고정은 손해

```
GPU 306 MHz → 1020 MHz (3.3배)   →   처리량 +9%,  전력 +424 mA(+24%)
```

전력당 처리량으로 보면 오히려 나빠진다.

```
병합만      12.3 tok/s / 1768 mA = 0.0070   ← 최적
클럭 고정   13.4 tok/s / 2192 mA = 0.0061
```

424 mA(약 2 W)를 9% 성능에 쓰는 것은 맞는 거래가 아니다. 클럭은 원복했다.

## 관찰 3 — 병목은 GPU 연산이 아니다

클럭을 3.3배 올렸는데 9%만 개선됐다는 것은 **연산이 병목이 아니라는 증거**다.
0.5B는 GPU 입장에서 너무 작아, 토큰마다 발생하는 **커널 런치 오버헤드**가
지배적인 것으로 판단했다. 다음 실험은 이 가설을 직접 겨냥한다.

→ `torch.compile(mode="reduce-overhead")` + static KV cache = CUDA Graphs 캡처

## 관찰 4 — torch.compile은 환경 제약으로 실패했다

가설 자체는 유효했지만 이 보드에서는 실행할 수 없었다. 두 단계로 막혔다.

**1차 (`fullgraph=True`)** — dynamo가 추적 불가로 예외:

```
torch._dynamo.exc.Unsupported:
  ALL_ATTENTION_FUNCTIONS[self.config._attn_implementation]
```

transformers가 attention 구현을 런타임 딕셔너리 조회로 고르는데, dynamo가
이를 따라가지 못한다. graph break를 허용하지 않아 그대로 중단됐다.

**2차 (`fullgraph=False`)** — 진짜 원인이 드러남:

```
RuntimeError: Cannot find a working triton installation.
```

inductor 백엔드는 Triton으로 GPU 커널을 생성한다. Triton이 없으니 컴파일이
전혀 일어나지 않았고, `suppress_errors=True` 탓에 조용히 eager로 폴백했다.

| | TTFT | E2E | tok/s |
|---|---|---|---|
| 병합만 | 87.0 ms | 2094.1 ms | 12.3 |
| + compile(폴백) | 91.5 ms | 2257.9 ms | **11.4** |

**7% 느려졌다.** 컴파일 이득은 0인데 static cache와 고정 길이 패딩의
오버헤드만 남았기 때문이다. 최적화를 켰다고 빨라지는 게 아니라는 확인이다.

설치도 불가능했다.

```
torch           2.4.0 (NVIDIA Jetson 빌드, aarch64)
요구 triton     3.0.0
pypi 제공       3.5.0 이상만
```

torch를 올리려면 JetPack L4T 패키지를 건드려야 하는데, CUDA 파손 위험이
있어 55개 패키지를 `apt-mark hold` 해둔 상태다. 이 경로는 닫았다.

> 부수 확인: 컨테이너의 pip이 커스텀 인덱스(`jetson.webredirect.org`)를
> 가리키고 있어 `Name or service not known`으로 실패한다. DNS 문제로
> 보이지만 아니다. `PIP_INDEX_URL=https://pypi.org/simple`로 우회된다.

## 관찰 5 — llama.cpp로 병목을 확인 사살

Triton이 막혔을 뿐 진단은 유효했으므로, C++ 런타임으로 같은 병목을 쳤다.
llama.cpp를 CUDA(sm_87)로 빌드하고 병합 모델을 GGUF로 변환했다.

### 생성 속도 (llama-bench, tg32, 전 레이어 GPU)

| 런타임 | 생성 tok/s | 프롬프트 tok/s | 크기 |
|---|---|---|---|
| transformers FP16 | 6.3 | - | 994 MB |
| transformers + 병합 | 12.3 | - | 957 MB |
| llama.cpp F16 | **38.87** | 2747 | 942 MB |
| llama.cpp Q8_0 | **108.20** | 3618 | 501 MB |
| llama.cpp Q4_K_M | 104.93 | 3597 | 374 MB |

**같은 F16 가중치, 같은 GPU에서 12.3 → 38.87 (3.2배).** 연산도 정밀도도
동일하고 달라진 것은 런타임뿐이다. 이 3.2배가 Python 인터프리터와 커널 런치
오버헤드였다는 직접 증거이고, 관찰 3의 가설을 확정한다.

양자화 구간은 성격이 다르다. F16 942 MB → Q8_0 501 MB로 절반이 되자 속도가
2.8배가 됐다. **메모리 대역폭이 병목**이라는 뜻이다. 다만 Q4_K_M은 374 MB로
더 작은데도 오히려 느리다(104.93). 역양자화 연산 비용이 대역폭 이득을
넘어선 것으로, **줄일수록 빨라지는 구간이 아니다.**

### 정확도 (테스트셋 150개 전체, evaluate.py의 score() 그대로 재사용)

| | parse | schema | sign | exact | 요청 지연 |
|---|---|---|---|---|---|
| transformers (기준) | 100 | 100 | 86.0 | **74.7%** | 2094 ms |
| llama.cpp F16 | 100 | 100 | 86.7 | **74.7%** | 787 ms |
| llama.cpp Q8_0 | 100 | 100 | 85.3 | 74.0% | **405 ms** |
| llama.cpp Q4_K_M | 100 | 100 | 86.0 | 74.0% | 408 ms |

채점기를 새로 만들지 않고 기존 `score()`를 그대로 import했다. 다른 채점기를
쓰면 비교 자체가 무의미해지기 때문이다.

**F16 GGUF의 값 정확도가 74.7%로 기준과 소수점까지 일치한다**(부호는 86.0 → 86.7로 한 건 차이). 변환이 모델을 훼손하지
않았다는 확인이고, 이것이 맞아야 아래 양자화 비교가 의미를 가진다.

**양자화 손실은 0.7%p에 그쳤고, Q4_K_M(4비트)이 Q8_0(8비트)과 동일한
74.0%다.** 절반으로 더 줄였는데 정확도가 떨어지지 않았다. 출력이 짧은
구조화된 JSON이라 양자화 노이즈에 둔감한 것으로 보인다.

### 선택: Q4_K_M

| | Q8_0 | Q4_K_M |
|---|---|---|
| 정확도 | 74.0% | 74.0% (동일) |
| 지연 | 405 ms | 408 ms (+0.7%) |
| 크기 | 501 MB | **374 MB** |

지연 차이가 1% 미만이고 정확도가 같으므로 크기가 작은 쪽을 택한다.
로봇에는 카메라·SLAM이 함께 올라가므로 메모리 여유가 성능보다 값지다.

## 최종

```
transformers FP16     4114 ms   994 MB   74.7%
llama.cpp Q4_K_M       408 ms   374 MB   74.0%
                    ─────────────────────────────
                      10.1배     62% 감소   -0.7%p
```

명령 하나를 4.1초에 변환하던 것이 0.41초가 됐다. 정확도는 0.7%p를 내줬다.

## 전력에 대한 정정 (2026-09-30 최종)

초기에는 "학습 중 2616 mA에서 전원 차단"으로 적고, 이후 "지속 부하" 가설로 고쳤다. **둘 다 틀렸다.**

- 전류 센서(ina3221 ch1 `VDD_IN`)는 19V 입력이 아니라 **모듈 5V 쪽(약 4.95V)**이다. 2616 mA ≈ 13 W,
  3784 mA ≈ 19 W. 번들 어댑터(19V 2.37A, 45W)에 한참 못 미친다
- 학습 중 리셋의 실제 원인은 **메모리 고갈**이었다. PyTorch 캐싱 할당기가 5.6 GB까지 불어나 시스템 RAM이
  170 MB로 떨어졌다. 할당기 상한(60%)으로 해결했다. 상세는 [README](README.md)의 "학습 중 보드 리셋"

## 실제 주행 경로에서 (2026-10-01)

llama-server를 상주시키고 `nl2cmdvel.sh`를 여기에 붙인 뒤, 문장 입력부터 ESP32 수신까지 쟀다.

### 드문드문 오는 요청에서는 클럭 고정이 이득이다

관찰 2와 결론이 반대다. 조건이 다르기 때문이다.

```
요청 간격 3초, 6회 (llama-server, Q4_K_M)
기본 거버너 (대기 306 MHz)      755 ~ 839 ms
최저 클럭 1020 MHz 고정         400 ~ 458 ms
대기 전력 (VDD_IN)              4.97 W → 5.81 W  (+0.84 W)
```

위의 408 ms는 150건을 **연달아** 보낸 평가에서 나왔다. 연속 부하라 거버너가 클럭을
올려둔 상태였다. 실제 명령은 몇 초 간격으로 오고, 요청 하나(약 0.5초)가 끝날 때까지
클럭이 올라오지 않는다. 서버 로그로도 토큰당 20.9 ms(48 tok/s)로, llama-bench의
105 tok/s의 절반이었다. 관찰 2는 transformers를 연속으로 돌린 측정이라 거버너가 이미
클럭을 올린 뒤를 비교한 셈이고, 그래서 차이가 9%에 그쳤다.

→ `scripts/llama_server.sh`가 **서버가 떠 있는 동안만** 최저 클럭을 최대로 고정하고,
종료할 때 원래대로 돌린다.

### 문장 → ESP32 전체 지연

```
명령 해석 (llama-server)                0.41 ~ 0.43 s
ROS 컨테이너 기동 + 구독자 연결           1.7 ~ 2.3 s
────────────────────────────────────────
문장 입력 → 첫 /cmd_vel 수신              2.2 ~ 2.7 s
```

이제 병목은 추론이 아니라 **명령마다 ROS 컨테이너를 새로 띄우는 비용**이다.

### 상주 브릿지로 ROS 기동 비용 제거

ROS 노드를 한 번 띄워 두고(`firmware/cmd_vel_bridge.py`), `nl2cmdvel.sh`는 로컬 TCP로
명령 한 줄만 넘기게 바꿨다. 같은 방식으로 다시 쟀다(리스너 타임스탬프, ESP32 연결 상태).

```
                              컨테이너 매번    상주 브릿지
문장 입력 → 첫 /cmd_vel 수신     2.2 ~ 2.7 s    0.57 ~ 0.63 s
정지어("멈춰") → 첫 정지 명령        —          0.17 s   (모델을 거치지 않는다)
2초 명령                       20회 + 정지     20회, 10.0 Hz + 정지 3회
5초 명령                       50회 + 정지     50회, 10.0 Hz + 정지 3회
```

- **달리는 중에 멈출 수 있게 됐다.** 예전에는 스크립트가 주행 시간만큼 붙잡혀 있어 다음 명령을
  보낼 수 없었다. 이제 새 명령이 진행 중인 명령을 덮어쓴다. 5초 회전 중 1.5초에 "멈춰" → 0.17초 뒤 정지
- 처음 만든 타이머는 다음 발행 시각을 `now + 0.1`로 잡아 틱(20 ms)만큼씩 밀렸다. 2초에 18회(약 9 Hz).
  예정 시각에 더하도록 고쳐 10.0 Hz
- 남은 0.6초 중 0.4초가 추론이고, 나머지는 파이썬 기동(해석기 두 번)과 DDS 전달이다

### 붙이면서 드러난 버그

- **주행 시간이 짧아졌다.** `timeout 2 ros2 topic pub`은 ROS 기동 시간(약 1초)까지
  2초에 넣어, "2초 동안 가"에 명령이 10개(1초 분량)만 나갔다. 구독자와 연결된 뒤부터
  시간을 재도록 바꾸고(`firmware/pub_cmd_vel.py`), 끝에 정지 명령을 보낸다.
  수정 후 2초 명령 → 20개 + 정지 3개, 발행 구간 2.11초
- **"멈춰"가 영원히 발행될 뻔했다.** duration 0을 `timeout 0`에 넘기면 '제한 없음'이다
- **컨테이너끼리 메시지가 안 넘어갔다.** Fast DDS가 같은 호스트로 보고 공유메모리를 쓰는데,
  컨테이너마다 `/dev/shm`이 달라 토픽은 보여도 데이터가 0건이었다. `--ipc=host`로 해결.
  micro-ROS Agent 컨테이너는 이 옵션 없이도 수신했다(Agent 로그로 확인)

## 남은 것

- ~~데이터 양 스윕 200/400~~ 완료(README 참고)
- ~~micro-ROS 노드에서 GGUF 추론 호출해 실제 제어 루프 지연 측정~~ 완료(위)
- ~~명령마다 ROS 컨테이너를 띄우는 비용(약 2초) 제거~~ 상주 브릿지로 0.6초(위)
- ~~주행과 무관한 문장("오늘 날씨 어때")에도 좌회전 명령을 낸다~~ 거부 학습으로 해결, 배포 모델 교체
  (`drive_cmd_rej_q4km.gguf`, [README](README.md#주행이-아닌-문장-거부-2026-10-01))

## 재현

```bash
# 기준선
python3 benchmark.py --adapter adapter --n 30 --label fp16
# 병합
python3 benchmark.py --adapter adapter --merge --n 30 --label fp16_merged
# 컴파일
python3 benchmark.py --adapter adapter --merge --compile --n 30
```

전력은 `monitor.sh`가 1초 간격으로 append+sync 기록한다. 보드가 갑자기
꺼져도 직전 수치가 디스크에 남도록 한 것이다.

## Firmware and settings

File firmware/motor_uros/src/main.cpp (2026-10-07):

/*
 * 로봇 주행 제어기 - micro-ROS 노드
 *
 * ROS 2의 /cmd_vel(geometry_msgs/Twist)을 구독해 좌우 바퀴 PWM으로 바꾼다.
 * Jetson에서 micro-ROS Agent를 띄우면 이 보드가 ROS 2 노드로 참여한다.
 *
 *   [상위]  /cmd_vel  ->  micro-ROS Agent  --USB시리얼-->  ESP32  ->  BTS7960
 *
 * 안전장치는 시리얼 버전과 같다. 명령이 끊기면 스스로 멈춘다.
 * 상위가 죽었을 때 마지막 속도로 계속 달리는 것이 가장 위험하기 때문이다.
 */
#include <Arduino.h>
#include <micro_ros_platformio.h>
#include <rcl/rcl.h>
#include <rclc/rclc.h>
#include <rclc/executor.h>
#include <geometry_msgs/msg/twist.h>

// --- 핀 배치 (시리얼 버전과 동일) ---
constexpr int L_RPWM = 25, L_LPWM = 26;
constexpr int R_RPWM = 32, R_LPWM = 33;
constexpr int LED    = 2;
// EN 핀은 펌웨어가 켠다. 점퍼선이 암-암뿐이라 3V3 한 핀을 VCC·R_EN·L_EN 여러 곳으로
// 나눌 수 없어서 EN을 GPIO에 하나씩 물렸다. 덕분에 micro-ROS 연결 전에는 드라이버가 꺼져 있다.
constexpr int L_R_EN = 27, L_L_EN = 18;
constexpr int R_R_EN = 16, R_L_EN = 17;
// 오른쪽 드라이버의 로직 전원(VCC). 3V3 핀은 왼쪽 드라이버가 쓴다.
// 로직부(74HC244 + BTS7960 입력)는 수 mA 이하라 GPIO로 공급한다. 브레드보드가 생기면 3V3로 옮길 것
constexpr int R_VCC = 23;
constexpr int CH_L_R = 0, CH_L_L = 1, CH_R_R = 2, CH_R_L = 3, CH_LED = 4;
constexpr int PWM_FREQ = 20000, PWM_BITS = 8;

// --- 로봇 치수 ---
// JGA25-370 12V 170RPM + 65mm 바퀴 기준 이론 최고속도:
//   170 / 60 * pi * 0.065 = 0.578 m/s
// 무부하 회전수라 실제로는 더 낮다. 박스 섀시 바닥 실측: 0.2 m/s x 1.5 s 명령에 27 cm(90%)
constexpr float MAX_SPEED   = 0.50f;   // m/s
constexpr float WHEEL_BASE  = 0.24f;   // m, 좌우 바퀴 중심 간격(박스 섀시 실측)
// 4륜 스키드 조향은 제자리 회전에서 바퀴가 옆으로 미끄러져 덜 돈다.
// 실측: 90도 명령에 45도(좌·우·좌 3회 같음). 속도 오차(90%)를 빼면 회전 효율 약 0.56
constexpr float TURN_EFF    = 0.56f;
constexpr float TRACK_EFF   = WHEEL_BASE / TURN_EFF;   // 약 0.43 m, 바퀴 속도 계산에 쓰는 유효 간격
// 좌우 모터가 거울상으로 달려서 배선이 같으면 오른쪽이 거꾸로 돈다(섀시 장착 후 확인)
constexpr bool  INVERT_R    = true;

constexpr uint32_t CMD_TIMEOUT_MS = 500;
volatile uint32_t last_cmd_ms = 0;
volatile bool stopped = true;

rcl_subscription_t sub_cmd_vel;
geometry_msgs__msg__Twist msg_in;
rclc_executor_t executor;
rclc_support_t support;
rcl_allocator_t allocator;
rcl_node_t node;

void applyMotor(int ch_fwd, int ch_rev, int duty) {
  duty = constrain(duty, -255, 255);
  if (duty >= 0) { ledcWrite(ch_rev, 0); ledcWrite(ch_fwd, duty); }
  else           { ledcWrite(ch_fwd, 0); ledcWrite(ch_rev, -duty); }
}

void driveStop() {
  applyMotor(CH_L_R, CH_L_L, 0);
  applyMotor(CH_R_R, CH_R_L, 0);
  ledcWrite(CH_LED, 0);
  stopped = true;
}

// Twist(선속도·각속도) -> 좌우 바퀴 속도. 차동 구동 변환.
void cmdVelCallback(const void *msgin) {
  const auto *m = (const geometry_msgs__msg__Twist *)msgin;
  float v = m->linear.x;      // m/s
  float w = m->angular.z;     // rad/s

  float v_l = v - w * TRACK_EFF / 2.0f;
  float v_r = v + w * TRACK_EFF / 2.0f;

  int duty_l = (int)(v_l / MAX_SPEED * 255.0f);
  int duty_r = (int)(v_r / MAX_SPEED * 255.0f);
  if (INVERT_R) duty_r = -duty_r;

  applyMotor(CH_L_R, CH_L_L, duty_l);
  applyMotor(CH_R_R, CH_R_L, duty_r);
  ledcWrite(CH_LED, min(255, max(abs(duty_l), abs(duty_r))));

  last_cmd_ms = millis();
  stopped = false;
}

void enableDrivers(bool on) {
  for (int pin : {L_R_EN, L_L_EN, R_R_EN, R_L_EN}) digitalWrite(pin, on ? HIGH : LOW);
}

void setup() {
  // 부팅 직후 EN이 떠 있지 않게 가장 먼저 LOW로 묶는다
  for (int pin : {L_R_EN, L_L_EN, R_R_EN, R_L_EN}) { pinMode(pin, OUTPUT); digitalWrite(pin, LOW); }
  pinMode(R_VCC, OUTPUT);
  digitalWrite(R_VCC, HIGH);

  ledcSetup(CH_L_R, PWM_FREQ, PWM_BITS); ledcAttachPin(L_RPWM, CH_L_R);
  ledcSetup(CH_L_L, PWM_FREQ, PWM_BITS); ledcAttachPin(L_LPWM, CH_L_L);
  ledcSetup(CH_R_R, PWM_FREQ, PWM_BITS); ledcAttachPin(R_RPWM, CH_R_R);
  ledcSetup(CH_R_L, PWM_FREQ, PWM_BITS); ledcAttachPin(R_LPWM, CH_R_L);
  ledcSetup(CH_LED, 1000, PWM_BITS);     ledcAttachPin(LED, CH_LED);
  driveStop();

  Serial.begin(115200);
  set_microros_serial_transports(Serial);
  delay(2000);

  allocator = rcl_get_default_allocator();
  rclc_support_init(&support, 0, NULL, &allocator);
  rclc_node_init_default(&node, "esp32_motor", "", &support);
  rclc_subscription_init_default(
      &sub_cmd_vel, &node,
      ROSIDL_GET_MSG_TYPE_SUPPORT(geometry_msgs, msg, Twist), "cmd_vel");

  rclc_executor_init(&executor, &support.context, 1, &allocator);
  rclc_executor_add_subscription(&executor, &sub_cmd_vel, &msg_in,
                                 &cmdVelCallback, ON_NEW_DATA);
  last_cmd_ms = millis();
  enableDrivers(true);   // PWM이 0인 상태에서 켠다 — 양쪽 LOW라 브레이크 상태
}

void loop() {
  rclc_executor_spin_some(&executor, RCL_MS_TO_NS(10));

  if (!stopped && millis() - last_cmd_ms > CMD_TIMEOUT_MS) {
    driveStop();   // 상위에서 명령이 끊겼다
  }
}

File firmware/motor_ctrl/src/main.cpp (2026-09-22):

/*
 * 모터 제어 펌웨어 - BTS7960(IBT-2) 2채널 구동용
 *
 * BTS7960은 정/역을 PWM 두 핀으로 나눠 받는다(RPWM/LPWM).
 * 한쪽에 듀티를 주는 동안 반대쪽은 반드시 0이어야 한다.
 * 둘 다 0이 아니면 하이사이드와 로우사이드가 동시에 열려
 * 드라이버가 단락된다(shoot-through).
 *
 * 드라이버가 아직 없어 출력은 온보드 LED로 확인한다.
 * 핀 번호와 신호 규격은 실제 배선과 같게 두었으므로,
 * 드라이버가 오면 배선만 연결하면 된다.
 *
 * 시리얼 명령(115200)
 *   L <-255..255>   왼쪽 속도
 *   R <-255..255>   오른쪽 속도
 *   S               즉시 정지
 *   ?               상태 출력
 */
#include <Arduino.h>

// --- 핀 배치 (BTS7960 2개) ---
constexpr int L_RPWM = 25;   // 왼쪽 정방향
constexpr int L_LPWM = 26;   // 왼쪽 역방향
constexpr int R_RPWM = 32;   // 오른쪽 정방향
constexpr int R_LPWM = 33;   // 오른쪽 역방향
constexpr int LED    = 2;    // 온보드 LED (드라이버 대용 확인)
// PWM이 실제로 나가는지 확인하기 위한 입력 핀.
// GPIO25(L_RPWM)와 점퍼선으로 연결하면 보드가 자기 출력을 자기가 읽는다.
// 오실로스코프나 로직 애널라이저 없이 듀티를 검증하기 위한 것이다.
constexpr int VERIFY_IN = 34;   // 입력 전용 핀

// --- LEDC(ESP32 하드웨어 PWM) 채널 ---
constexpr int CH_L_R = 0, CH_L_L = 1, CH_R_R = 2, CH_R_L = 3, CH_LED = 4;
constexpr int PWM_FREQ = 20000;   // 20kHz - 가청대역 위. 모터 소음을 줄인다
constexpr int PWM_BITS = 8;       // 0~255

// --- 안전장치 ---
constexpr uint32_t CMD_TIMEOUT_MS = 500;   // 이 시간 명령이 없으면 정지
uint32_t last_cmd_ms = 0;
int speed_l = 0, speed_r = 0;
bool stopped_by_timeout = false;

void applyMotor(int ch_fwd, int ch_rev, int speed) {
  speed = constrain(speed, -255, 255);
  // 한쪽을 먼저 0으로 내린 뒤 반대쪽을 올린다. 순서가 바뀌면 순간적으로 양쪽이 살아난다
  if (speed >= 0) {
    ledcWrite(ch_rev, 0);
    ledcWrite(ch_fwd, speed);
  } else {
    ledcWrite(ch_fwd, 0);
    ledcWrite(ch_rev, -speed);
  }
}

void applyAll() {
  applyMotor(CH_L_R, CH_L_L, speed_l);
  applyMotor(CH_R_R, CH_R_L, speed_r);
  // 드라이버가 없으므로 두 바퀴 중 큰 쪽 세기를 LED 밝기로 보여준다
  ledcWrite(CH_LED, max(abs(speed_l), abs(speed_r)));
}

void stopAll(const char* why) {
  speed_l = speed_r = 0;
  applyAll();
  Serial.printf("STOP (%s)\n", why);
}

void verifyPwm() {
  // PWM 한 주기(20kHz = 50us)보다 훨씬 오래 표본을 모아
  // HIGH로 읽힌 비율을 센다. 샘플링이 PWM과 동기화돼 있지 않으므로
  // 표본이 충분하면 그 비율이 듀티에 수렴한다.
  Serial.println("duty,measured,expected,error");
  const int duties[] = {0, 32, 64, 96, 128, 160, 192, 224, 255};
  for (int d : duties) {
    ledcWrite(CH_L_L, 0);
    ledcWrite(CH_L_R, d);
    delay(80);                       // 출력이 안정될 때까지 기다린다
    const uint32_t N = 20000;
    uint32_t high = 0;
    for (uint32_t i = 0; i < N; i++) {
      if (digitalRead(VERIFY_IN)) high++;
    }
    float measured = (float)high / N;
    float expected = (float)d / 255.0f;
    Serial.printf("%d,%.4f,%.4f,%+.4f", d, measured, expected, measured - expected);
    Serial.println();
  }
  ledcWrite(CH_L_R, 0);
  Serial.println("verify_done");
}

void setup() {
  Serial.begin(115200);
  delay(200);
  pinMode(VERIFY_IN, INPUT);

  ledcSetup(CH_L_R, PWM_FREQ, PWM_BITS); ledcAttachPin(L_RPWM, CH_L_R);
  ledcSetup(CH_L_L, PWM_FREQ, PWM_BITS); ledcAttachPin(L_LPWM, CH_L_L);
  ledcSetup(CH_R_R, PWM_FREQ, PWM_BITS); ledcAttachPin(R_RPWM, CH_R_R);
  ledcSetup(CH_R_L, PWM_FREQ, PWM_BITS); ledcAttachPin(R_LPWM, CH_R_L);
  ledcSetup(CH_LED, 1000, PWM_BITS);     ledcAttachPin(LED, CH_LED);

  stopAll("boot");
  last_cmd_ms = millis();
  Serial.println("ready: L/R <-255..255>, S=stop, ?=status, V=verify PWM");
}

void handleLine(String line) {
  line.trim();
  if (!line.length()) return;
  char c = toupper(line[0]);

  if (c == 'S') { stopAll("command"); last_cmd_ms = millis(); return; }
  if (c == 'V') { verifyPwm(); last_cmd_ms = millis(); return; }
  if (c == '?') {
    Serial.printf("L=%d R=%d  timeout=%s  since_cmd=%lums\n",
                  speed_l, speed_r, stopped_by_timeout ? "Y" : "N",
                  millis() - last_cmd_ms);
    return;
  }
  if (c == 'L' || c == 'R') {
    int v = line.substring(1).toInt();
    if (c == 'L') speed_l = constrain(v, -255, 255);
    else          speed_r = constrain(v, -255, 255);
    applyAll();
    last_cmd_ms = millis();
    stopped_by_timeout = false;
    Serial.printf("OK L=%d R=%d\n", speed_l, speed_r);
    return;
  }
  Serial.println("ERR unknown command");
}

void loop() {
  while (Serial.available()) {
    static String buf;
    char ch = Serial.read();
    if (ch == '\n' || ch == '\r') { handleLine(buf); buf = ""; }
    else if (buf.length() < 32)   { buf += ch; }
  }

  // 명령이 끊기면 스스로 멈춘다.
  // 상위 제어기가 죽거나 USB가 빠져도 마지막 속도로 계속 달리지 않게 하기 위함이다.
  if (!stopped_by_timeout && (speed_l || speed_r) &&
      millis() - last_cmd_ms > CMD_TIMEOUT_MS) {
    stopped_by_timeout = true;
    stopAll("timeout");
  }
}

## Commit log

2026-09-18 Jetson Orin Nano + ESP32 로봇 개발 환경 구축
    - Jetson 셋업: JetPack 6.2, Docker data-root를 NVMe로 이전, L4T 패키지 고정
    - micro-ROS Agent 컨테이너 구동 및 시리얼 통신 계층 검증 스크립트
    - 하드웨어 사양 선정 근거와 전원 분리 설계 문서화
2026-09-18 셸 스크립트 줄바꿈을 LF로 고정 (Jetson에서 실행)
2026-09-21 ESP32 모터 제어 펌웨어와 주행 명령 파인튜닝 추가
    자연어 주행 명령을 로봇 제어 명령으로 바꾸고, 그 결과를 마이크로컨트롤러까지
    전달하는 경로를 구성했다.
    자연어 → LoRA 모델 → JSON → ROS 2 /cmd_vel → micro-ROS → ESP32 → PWM
    firmware/
    - motor_ctrl: 시리얼 명령으로 BTS7960 2채널을 구동하는 펌웨어.
    RPWM/LPWM을 동시에 올리지 않도록 순서를 강제해 드라이버 단락을 막고,
    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
2026-09-22 PWM 자가검증 추가와 펌웨어 문서화
    계측 장비 없이 PWM 출력을 확인할 방법이 필요했다. 보드에 사용자 LED가 없고
    오실로스코프도 로직 애널라이저도 없어서, 출력 핀을 입력 핀에 점퍼선으로 연결해
    보드가 자기 출력을 자기가 읽게 했다.
    PWM 한 주기(20kHz = 50us)보다 훨씬 긴 시간 동안 20,000번 샘플링해 HIGH 비율을
    센다. 샘플링이 PWM과 동기화돼 있지 않으므로 표본이 충분하면 비율이 듀티에 수렴한다.
    측정 결과 9개 지점 모두 선형이었고 최대 오차는 1.25%p였다(duty 160).
    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
2026-09-30 엣지 추론 최적화: transformers 4.1초 → llama.cpp Q4 0.41초
    - benchmark.py: 배치 1 요청당 지연·TTFT·tok/s·VRAM 측정 (--merge, --compile)
    - LoRA 가중치 병합 2.0배, GPU 클럭 고정은 +9%에 전력 +24%라 기각
    - torch.compile은 Triton 부재(torch 2.4 / triton 3.0 미제공)로 적용 불가, 기록만 남김
    - llama.cpp CUDA(sm_87) 빌드 + GGUF 변환·양자화: 같은 F16에서 3.2배, Q8/Q4에서 2.8배
    - eval_gguf.py: 기존 score()를 그대로 써서 정확도 비교 — F16 74.7%(동일), Q4_K_M 74.0%
    - BENCHMARK.md: 측정 전문과 병목별 해석
2026-09-30 학습 중 보드 리셋 원인(메모리) 해결과 데이터 양 스윕
    학습이 9스텝 근처에서 OOM kill되거나 보드가 로그 없이 재부팅됐다.
    스텝별 계측 결과 PyTorch 실사용은 1.06GB로 일정한데 캐싱 할당기의
    reserved가 5.6GB까지 불어 시스템 RAM이 170MB로 떨어졌다(Jetson은 GPU가
    시스템 RAM을 공유). 전원 부족으로 본 초기 판단은 센서가 5V 쪽이라 틀렸다.
    - train_lora.py: --mem-fraction(기본 0.6)으로 할당기 상한, --memlog 스텝별 기록
    - run_*.sh: PYTORCH_CUDA_ALLOC_CONF=garbage_collection_threshold:0.6
    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
2026-09-30 README: 전체 성과 요약과 진행 상황 갱신
    - 상단에 영역별 결과 표(펌웨어·학습·평가·엣지 추론·장애 진단)와 하위 문서 링크
    - 자연어 → /cmd_vel → ESP32 전체 흐름도. llama.cpp 연결은 다음 단계로 명시
    - 진행 상황을 실제 상태로 갱신: 펌웨어·micro-ROS·파인튜닝·최적화 완료, 조립·실주행 전
    - 저장소 구조, 메모리 상한, 환경(PyTorch·llama.cpp) 추가
2026-09-30 llama.cpp 추론을 /cmd_vel 경로에 연결, 문장 → ESP32 수신 실측
    nl2cmdvel.sh가 명령마다 transformers 컨테이너를 띄우던 것을 상주
    llama-server(Q4_K_M)에 묻도록 바꿨다. 문장 → ESP32 첫 명령 수신 2.2~2.7초,
    그중 추론 0.42초이고 나머지는 ROS 컨테이너 기동이다.
    - infer.py: --server 모드(표준 라이브러리만, 호스트 python3). 숫자·유한값·
    duration 0~10초 검증 추가. transformers 경로는 비교용으로 유지
    - llama_server.sh: 서버가 떠 있는 동안만 GPU 최저 클럭 고정, 종료 시 원복.
    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
2026-09-30 주행이 아닌 문장 거부 학습: 비주행 입력에 움직이는 비율 57~100% → 0%
    경로를 붙여 보니 "오늘 날씨 어때"에도 좌회전 명령이 나왔다. 학습
    데이터가 전부 주행 명령이라 모든 입력을 주행으로 읽었다. 기존 모델은
    비주행 문장 60개 중 잡담 57%, 주행 어휘가 든 문장("뒤로 가기 버튼
    눌러줘") 100%에서 움직이는 명령을 냈다.
    - offtopic.py: 거부 문장 학습용 191 / 평가용 60, 문장 단위 분리.
    평가용에 학습에 없는 유형 포함. 정지 단어가 든 문장은 일부러 제외
    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
2026-09-30 정지어 규칙과 상주 /cmd_vel 브릿지: 문장 → ESP32 2.5초 → 0.6초
    정지어 규칙
    - 거부 학습 모델이 처음 보는 정지어 "세워"를 거부했다. infer.py가
    정지어를 보면 모델을 부르지 않고 바로 정지 명령을 낸다. llama-server가
    없어도 동작한다. 테스트 150건에서 정지 아닌 명령 오탐 0건
    - report_reject.py에 "+ 정지어 규칙" 줄: 완전일치 72.0, 잘못 거부 0.7%
    상주 브릿지 (firmware/cmd_vel_bridge.py, scripts/cmd_bridge.sh)
    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
2026-10-01 시드 반복·확신도 되묻기: 단일 비교의 "-3.4%p"는 편차였다
    시드 반복 (run_seeds.sh, report_seeds.py, train_lora.py --seed)
    - 기존·거부 학습을 시드만 바꿔 3번씩 학습. 같은 설정도 70~80%로 흔들린다.
    평균 완전일치 기존 72.0±2.9 / 거부 77.8±2.3, 부호 84.4 / 91.8
    - 앞서 적은 "거부 학습 후 -3.4%p"는 운 좋은 기존(74.7)과 운 나쁜 거부(71.3)를
    맞붙인 결과였다. 처음 실행까지 넣으면 차이는 편차 안이라 결론을
    "거부 학습은 정확도를 잃지 않는다"로 정정
    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
2026-10-03 드라이버 EN을 펌웨어가 제어, 실물 배선 확인 (모터 4개 구동)
    - motor_uros: EN 핀을 GPIO로(L: 27/18, R: 16/17). 부팅 직후 LOW로 묶고
    micro-ROS 연결이 끝난 뒤 HIGH. 점퍼가 암-암뿐이라 3V3을 여러 갈래로 나눌 수
    없어서 택했는데, 상위 연결 전에는 드라이버가 꺼져 있는 이점도 생겼다
    - R 드라이버 로직 전원은 GPIO23 HIGH (로직부 수 mA 이하)
    - README: 실물로 확인한 핀 표, HW-039 헤더 방향, 출력 단자 앞/뒷면 순서
    (모터를 B+/B-에 물리면 명령과 무관하게 돈다 — 실제로 겪음), 모터 6핀 배치
    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
2026-10-03 1.5B 비교 시도 기록: Jetson 8GB에서는 학습 불가 (메모리)
    - run_1p5b.sh: 0.5B 거부 학습과 같은 데이터·시드 3개로 Qwen2.5-1.5B 비교.
    가용 메모리 300MB 아래로 내려가면 컨테이너를 멈추는 감시 포함
    - 결과: fp16 가중치 3.17GB로 가용 메모리 196~297MB(배치 1·2 동일, 9/23 리셋 때
    170MB) → 첫 스텝부터 감시가 중단. QLoRA는 PyPI bitsandbytes가 sm_87에서 커널
    실패(named symbol not found). 큰 GPU에서 학습 후 어댑터만 가져오는 용도로 남김
    - save_merged.py --base, report_seeds.py 1.5B 행 지원
2026-10-07 Invert right motor and set measured wheel base for box chassis
    Mounted mirror-image on the chassis, the right side spun backward with the
    same wiring as the left. Flip it in firmware instead of rewiring, and use
    the measured 0.24 m center-to-center wheel spacing.
    [main.cpp]
2026-10-07 Calibrate turn slip and top speed on the box chassis
    Skid steering turned only 45 degrees for a 90-degree command (same on three
    runs), and straight driving covered 27 of 30 cm. Widen the effective track
    by a 0.56 turn efficiency and lower MAX_SPEED to 0.50 m/s; a re-test turned
    just over 90 degrees.
    [main.cpp]
2026-10-08 Add laser-cut drawing for a two-deck acrylic chassis
    Dimensions come from the box chassis that already drives: bracket holes,
    wire holes and component footprints were measured on it. The script
    writes the DXF for the cutting shop and an SVG/PNG preview.
    [chassis.dxf]
2026-10-12 Use only round holes in the chassis drawing
    The cutting shop can drill plain round holes but not slots or grooves.
    The USB pass-through becomes a 22 mm hole, the power bank is strapped
    with cable ties through small holes, and the slotted camera plate is
    dropped for now (two M3 holes mark where a camera mount will go).
2026-11-03 Correct README facts: brake not short, EN timing, current status
    - BTS7960 both inputs on = brake, not shoot-through (dead time is inside the chip)
    - EN goes HIGH after micro-ROS init is called (success is not checked), with PWM at 0
    - 'spoken' commands -> text commands; status updated to 11/3 (floor driving with
    direct /cmd_vel, acrylic chassis, battery + Wi-Fi). Text-command floor driving not done yet
2026-11-03 Recalibrate turn for acrylic chassis and log text-command floor driving
    - TURN_EFF 0.56 -> 0.47: 0.56 gave 65.9 deg for a 90 deg command; the
    proportional guess 0.41 overshot to 112.2 deg (less slip at higher wheel
    speed), so interpolate between the two points
    - Straight line unchanged: 30 cm command -> 29.7 / 29.2 cm (left/right, 3 runs)
    - README: text commands now drive the robot on the floor over Wi-Fi on battery
    (forward, turn, non-driving sentence ignored, stop while moving in 0.16 s)
2026-11-05 Add camera stream and vision-based forward stop
    - vision/cam_stream.py: IMX219 (CSI) -> nvjpegenc -> MJPEG over HTTP (~28 fps at 1280x720),
    /snapshot.jpg and /health; Tailscale-only via the Jetson firewall
    - vision/obstacle_guard.py: learn the floor colour in front of the robot at start
    (Lab mean/covariance), find the lowest non-floor pixel per column in the robot's
    corridor, and block forward motion when it crosses the ~30 cm line
    (HSV histogram first marked wood grain and lighting changes as obstacles)
    - cmd_vel_bridge.py: {"block": true/false} cancels forward motion and rejects new
    forward commands while blocked; turning and reversing still allowed; no auto-resume
    Test: 0.15 m/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
2026-11-05 Move the stop line with speed so the robot stops 30 cm short at any speed
    - Bridge answers {"status": true} with the current forward speed
    - Guard triggers at 30 cm + v*0.17 s + v^2*0.91 (s^2/m), converted to an image row
    with the ground-plane relation (y - horizon) = k / distance (30 cm and 20 cm marks)
    - Linear-only lag (0.2 s) stopped at 23 cm from 0.3 m/s: overshoot was 4.6 cm at
    0.15 m/s but 13.3 cm at 0.3 m/s, so braking distance grows with v^2
    - Result at 0.3 m/s toward a box 80 cm ahead: stopped 30 cm (left) / ~31 cm (right) short
    - Correction to 26d9eef: that test's box was 60 cm ahead, not 1 m (moved 33 cm, stopped 27 cm short)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
2026-11-05 Read both front wheel encoders with PCNT and publish /wheel_ticks
    - motor_uros: hardware pulse counter (x4 quadrature) on the front-left (36/39) and
    front-right (34/35) encoders; encoder power and ground come from GPIOs (13/14, 4/15)
    because the board has no spare 3V3/GND pins; publishes cumulative [left, right]
    counts as std_msgs/Int32MultiArray at 20 Hz (best effort), left sign flipped so
    forward is positive on both sides
    - encoder_test: serial-only firmware used to check wiring one encoder at a time
    - One wheel turn by hand: +1539 / +1486 (1540 expected)
    - 0.2 m/s x 1.5 s drive: 2163 / 2144 counts; tape measure 30.0 / 29.7 cm vs 28.7 / 28.4 cm
    computed with the catalogue 65 mm w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
